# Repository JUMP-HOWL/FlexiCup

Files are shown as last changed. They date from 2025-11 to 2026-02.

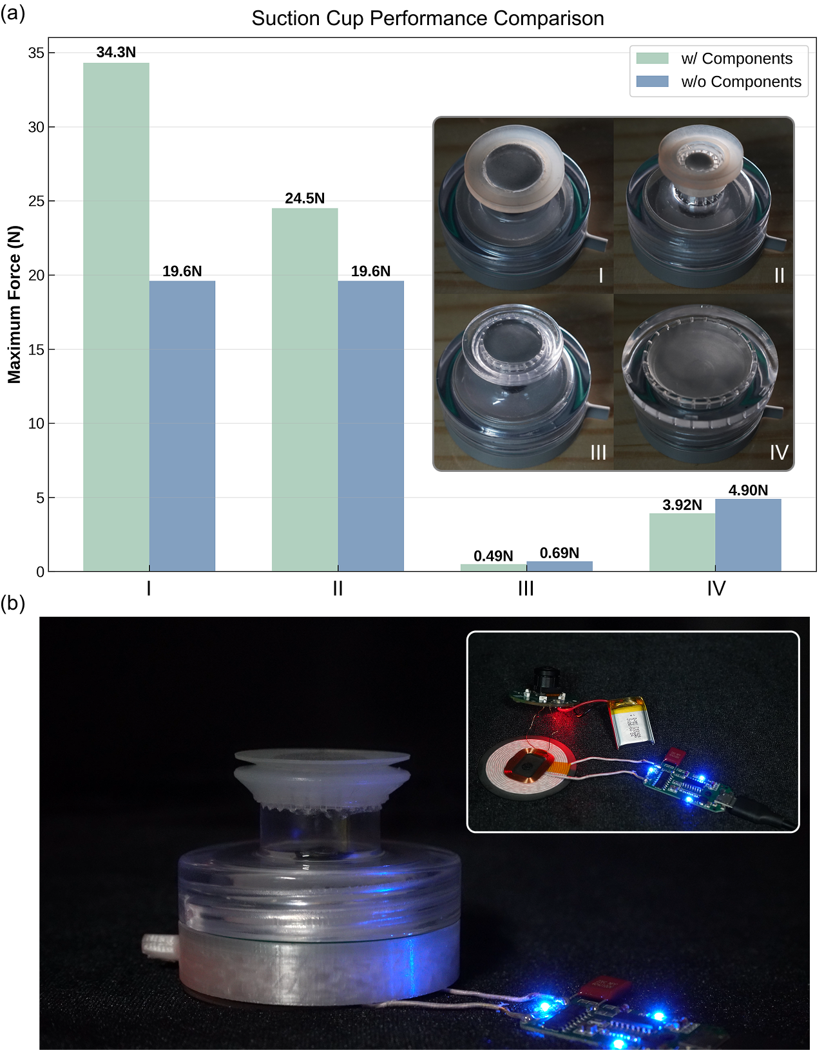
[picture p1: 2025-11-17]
static/images/image/FigBasicCharacterization.png

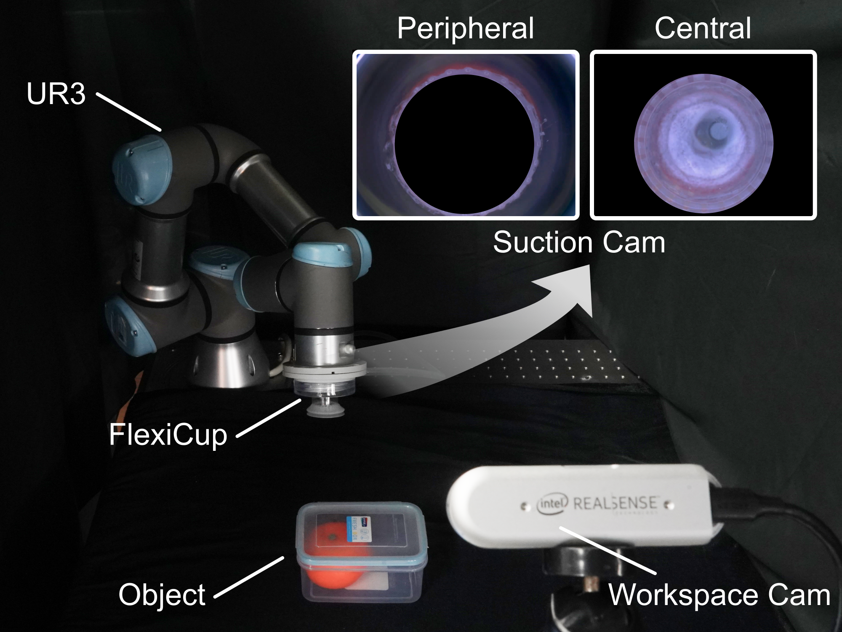
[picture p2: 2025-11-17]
static/images/image/FigExperimentSetup.png

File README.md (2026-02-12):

# FlexiCup: Wireless Multimodal Suction Cup with Dual-Zone Vision-Tactile Sensing

This repository contains the complete project files for FlexiCup—a multimodal suction cup with wireless electronics that integrates dual-zone vision-tactile sensing. The modular mechanical design supports both vacuum and Bernoulli actuation modes while maintaining the identical sensing architecture, demonstrating sensing-actuation decoupling. Included are hardware designs (CAD/STEP, PCB schematics/layout/BOM/Gerber), ESP32-S3 firmware, the full learning pipeline, and documentation.

## 📁 Repository Structure

```
FlexiCup/
├── Hardware/              # Hardware design and firmware
│   ├── Fabrication/       # Physical hardware design files
│   │   ├── CAD/          # 3D CAD models and mechanical designs
│   │   │   ├── FlexiCup_Vacuum.STEP          # Vacuum mode assembly (109MB)
│   │   │   ├── FlexiCup_Bernoulli.STEP       # Bernoulli mode assembly (109MB)
│   │   │   ├── suction cup bottom I.STEP     # Bottom configuration I
│   │   │   ├── suction cup bottom II.STEP    # Bottom configuration II
│   │   │   ├── suction cup bottom III.STEP   # Bottom configuration III
│   │   │   ├── suction cup bottom IV.STEP    # Bottom configuration IV
│   │   │   ├── suction cup top.STEP          # Top assembly
│   │   │   └── FlexiCup_CAD_BOM.xlsx        # CAD Bill of Materials
│   │   │
│   │   └── PCB/          # PCB design files
│   │       ├── FlexiCup_Schematic.pdf        # Circuit schematic
│   │       ├── FlexiCup_PCB.pdf              # PCB layout
│   │       ├── FlexiCup_PCB_BOM.xlsx         # PCB Bill of Materials
│   │       └── Gerber_PCB.zip                # Manufacturing files
│   │
│   └── Firmware/          # Embedded firmware code
│       └── ESPCAM/       # ESP32S3 camera firmware
│           ├── main/     # Main application code
│           │   ├── inc/  # Header files
│           │   │   ├── camera.h
│           │   │   ├── httpServer.h
│           │   │   ├── led.h
│           │   │   └── wifiConnect.h
│           │   ├── src/  # Source files
│           │   │   ├── camera.c
│           │   │   ├── httpServer.c
│           │   │   ├── led.c
│           │   │   └── wifiConnect.c
│           │   ├── html/ # Web interface
│           │   └── main.c # Main entry point
│           │
│           ├── managed_components/  # ESP32-Camera library
│           ├── CMakeLists.txt
│           ├── sdkconfig
│           └── README.md
│
├── Software/              # High-level software and algorithms
│   └── diffusion_policies/ # Diffusion policy implementation
│       ├── data_collect.py  # Data collection pipeline
│       ├── train.py        # Training script
│       ├── deploy.py       # Deployment script
│       ├── environment.yml # Conda environment
│       └── README.md       # Software documentation
│
├── PDF/                   # Documentation
│   └── paper.pdf         # Research paper
│
├── static/               # Website assets
│   ├── css/             # Stylesheets
│   ├── js/              # JavaScript files
│   ├── images/          # Images and figures
│   └── video/           # Video demonstrations
│       ├── optimized/   # Optimized videos for web (12.2MB total)
│       └── websitevideo/# Original high-quality videos
│
└── index.html           # Project website

```

## 🔧 Hardware Files

### Fabrication Design Files
All mechanical and electronic designs are provided for complete system reproduction:

**CAD Models (STEP Format)**
All mechanical designs are provided in STEP format for maximum compatibility:

- **Main Assemblies**:
  - `FlexiCup_Vacuum.STEP` (109MB): Complete vacuum suction mode assembly
  - `FlexiCup_Bernoulli.STEP` (109MB): Complete Bernoulli suction mode assembly

- **Modular Components**:
  - `suction cup top.STEP`: Top housing with camera and electronics
  - `suction cup bottom I-IV.STEP`: Four interchangeable bottom configurations
    - I & II: For vacuum mode operation
    - III & IV: For Bernoulli mode operation

- **Bill of Materials**:
  - `FlexiCup_CAD_BOM.xlsx`: Complete list of mechanical components

**PCB Design Files**
Complete electronics design for the FlexiCup controller:

- **Schematic**: `FlexiCup_Schematic.pdf` - Circuit diagram
- **Layout**: `FlexiCup_PCB.pdf` - PCB layout design
- **BOM**: `FlexiCup_PCB_BOM.xlsx` - Electronic components list
- **Manufacturing**: `Gerber_PCB.zip` - Gerber files for PCB fabrication

**Key Components**:
- ESP32S3 microcontroller with Wi-Fi
- OV5640 camera interface
- LED driver circuits
- Power management (3.7V LiPo battery)
- Wireless charging circuit

### Firmware Code

**ESP32S3 Camera Firmware**
Located in `Hardware/Firmware/ESPCAM/`, built with ESP-IDF framework.

**Main Features**:
- **Camera Control** (`camera.c/h`): OV5640 camera configuration and image capture
- **LED Control** (`led.c/h`): Illumination switching for vision-tactile sensing
- **HTTP Server** (`httpServer.c/h`): Web interface and video streaming
- **Wi-Fi** (`wifiConnect.c/h`): Wireless communication

**Key Specifications**:
- Image Resolution: 640×480 @ 30 Hz
- Streaming: Real-time video over Wi-Fi (UDP)
- Power: 3.7V 300mAh LiPo battery with wireless charging
- Runtime: ~30 minutes continuous operation

**Building the Firmware**
```bash
cd Hardware/Firmware/ESPCAM
idf.py build
idf.py flash
```

## 💻 Software

### Diffusion Policy Implementation
Located in `Software/diffusion_policies/`, this contains the complete machine learning pipeline for contact-aware manipulation.

**Main Components**:
- **Data Collection** (`data_collect.py`): Automated data collection pipeline for demonstration gathering
- **Training** (`train.py`): Diffusion policy training with multimodal observations
- **Deployment** (`deploy.py`): Real-time deployment for robot control
- **Environment** (`environment.yml`): Conda environment with all dependencies

**Key Features**:
- Multimodal fusion of dual-zone vision-tactile data via multi-head attention (8 heads, 512-d)
- Diffusion policy with action chunking (8-step history, 48-step horizon)
- AdamW optimizer with cosine annealing, 500 epochs training
- Real-time inference for robot control at 10 Hz
- Contact-aware manipulation with illumination switching and valve control

**Setup and Usage**
```bash
cd Software/diffusion_policies
conda env create -f environment.yml
conda activate flexicup
python train.py --config configs/flexicup_config.yaml
```

## 📊 System Specifications

### Mechanical
- **Normal Force**: 41.5 N (mean, at −80 kPa vacuum)
- **Shear Force**: 8.34 N (mean)
- **Modes**: Vacuum (sustained-contact adhesion) and Bernoulli (contactless lifting)
- **Configurations**: 4 modular bottom designs (I–II vacuum, III–IV Bernoulli)
- **Material**: Dual-layer PDMS membrane (30:1 base + Ag:PDMS 100:1 reflective layer)

### Electronics
- **Controller**: ESP32-S3 (dual-core, Wi-Fi enabled)
- **Camera**: OV5640 with 180° fisheye lens
- **Resolution**: 640×480 @ 30 Hz
- **Connectivity**: Wi-Fi 802.11 b/g/n (UDP streaming)
- **Power**: 3.7V 300mAh LiPo with wireless charging (12.5 μH coil, 200 mA)
- **Runtime**: ~30 minutes continuous operation

### Sensing
- **Dual-Zone**: Central (switchable vision-tactile via LED control) + Peripheral (continuous spatial awareness)
- **Modality Switching**: Real-time illumination control by ESP32-S3
- **Multimodal Recognition**: 100% accuracy (vs. vision-only 82.5%, tactile-only 46.7%)

## 📄 Documentation

- **Research Paper**: `PDF/paper.pdf`
- **Tutorial**: `TUTORIAL.pdf` - Complete fabrication and deployment guide
- **Companion Website**: `index.html` (view at https://jump-howl.github.io/FlexiCup/)
- **Hardware README**: `Hardware/README.md`
- **Software README**: `Software/diffusion_policies/README.md`

## 🎥 Video Demonstrations

Optimized videos are available in `static/video/optimized/`:
- `overview.mp4`: System overview
- `integrated_show.mp4`: Hardware integration and assembly
- `multimodal_performance.mp4`: Vision-tactile sensing demonstration
- `modular_task.mp4`: Modular perception-driven grasping (vacuum & Bernoulli)
- `dptask1.mp4`: Inclined transport task (diffusion policy)
- `dptask2.mp4`: Orange extraction task (diffusion policy)
- `baseline1.mp4` / `baseline2.mp4`: BC-RNN baseline comparisons
- `Wafer_Bernoulli.mp4` / `Wafer_Vaccum.mp4`: Wafer handling comparison
- `Move_Orange.mp4` / `Move_Bottle.mp4`: Dynamic performance evaluation

## 🚀 Getting Started

### Hardware Assembly
1. Review CAD models in `Hardware/Fabrication/CAD/`
2. Fabricate PCB using files in `Hardware/Fabrication/PCB/`
3. Follow BOM files for component sourcing
4. Assemble according to CAD models

### Firmware Setup
1. Install ESP-IDF framework
2. Navigate to `Hardware/Firmware/ESPCAM/`
3. Configure Wi-Fi settings in `main/src/wifiConnect.c`
4. Build and flash firmware

### Software Setup
1. Set up the diffusion policy environment:
   ```bash
   cd Software/diffusion_policies
   conda env create -f environment.yml
   conda activate flexicup
   ```
2. Collect training data or use provided datasets
3. Train the diffusion policy model
4. Deploy for real-time robot control

### Testing
1. Power on the device
2. Connect to FlexiCup Wi-Fi network
3. Access web interface via browser
4. Test vision and tactile sensing modes
5. Run software algorithms for manipulation tasks

<!-- ## 📝 Citation

If you use this work in your research, please cite:

```bibtex
@article{flexicup2025,
  title={FlexiCup: Wireless Multimodal Suction Cup with Dual-Zone Vision-Tactile Sensing},
  author={Anonymous},
  journal={Under Review},
  year={2025}
}
``` -->

## 📧 Contact

For questions or collaboration inquiries, please refer to the paper for contact information.

## 📜 License

This project is licensed under Creative Commons Attribution-ShareAlike 4.0 International License.

---

**Note**: Large CAD files (*.STEP) are managed with Git LFS. Clone with `git lfs clone` to download all files.

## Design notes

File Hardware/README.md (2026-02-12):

# FlexiCup Hardware

This directory contains all hardware-related files for the FlexiCup system, including physical fabrication designs and embedded firmware.

## Directory Structure

- **Fabrication/**: Physical hardware design files
  - **CAD/**: 3D mechanical designs (STEP format) and BOM
  - **PCB/**: Electronic circuit schematics, layout, BOM, and Gerber files
- **Firmware/**: ESP32-S3 embedded firmware
  - **ESPCAM/**: Camera control, LED switching, and wireless communication

## Overview

The FlexiCup hardware implements a modular layered architecture:

1. **Mechanical System**: Modular suction cup with reconfigurable bottom housings supporting vacuum (sustained-contact adhesion) and Bernoulli (contactless lifting) modes. Four bottom configurations (I–IV) accommodate different membrane diameters and actuation principles.
2. **Electronics**: ESP32-S3 controller with OV5640 camera (180° fisheye), WS2812 LED arrays, wireless charging (3.7V 300mAh LiPo), streaming 640×480 @ 30 Hz over Wi-Fi.
3. **Pneumatic System**: Vacuum pump (750 W, 140 L/min, −90 kPa max) and air compressor (800 W, 65 L/min, 0.8 MPa) for the respective modes. Solenoid valves controlled wirelessly by the onboard microcontroller.

## Key Performance

- **Normal Force**: 41.5 N (mean, at −80 kPa)
- **Shear Force**: 8.34 N (mean)
- **Sensing**: Dual-zone vision-tactile (central switchable + peripheral continuous)
- **Runtime**: ~30 minutes wireless operation

## Getting Started

### Fabrication
1. Review CAD models in `Fabrication/CAD/`
2. Fabricate PCB using files in `Fabrication/PCB/`
3. Source components according to BOM files
4. Assemble following the CAD designs

### Firmware
1. Install ESP-IDF framework (v5.0.2)
2. Navigate to `Firmware/ESPCAM/`
3. Configure Wi-Fi settings and build
4. Flash to ESP32-S3 device

For detailed fabrication and assembly instructions, see `TUTORIAL.pdf` in the repository root.

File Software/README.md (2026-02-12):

# FlexiCup Software

This directory contains the high-level software components for the FlexiCup system, focusing on diffusion-based policy learning for contact-aware manipulation.

## Directory Structure

- **diffusion_policies/**: Complete diffusion policy implementation
  - Data collection pipeline (keyboard teleoperation)
  - Training scripts and Hydra configurations
  - Evaluation and deployment code

## Overview

The FlexiCup software stack provides:

1. **Multimodal Observation Encoding**: Workspace camera (D435), dual-zone suction camera (peripheral + central), and robot state processed through parallel ResNet-18 encoders
2. **Multi-Head Attention Fusion**: 8-head, 512-d attention coordinating central and peripheral features during vision-tactile transitions
3. **Diffusion Policy**: DDPM-based action generation with action chunking (8-step history, 48-step horizon), outputting robot joints, illumination switching, and valve state
4. **Training**: AdamW optimizer with cosine annealing, 500 epochs, batch size 16 on RTX 4090

## Experimental Results

- **Inclined Transport**: 73.3% success rate (150 demos, 30 eval trials)
- **Orange Extraction**: 66.7% success rate (100 demos, 30 eval trials)
- **Multi-head attention improvement**: +13% over baseline without attention
- **BC-RNN baseline**: 0% success on both tasks

## Getting Started

### Environment Setup
```bash
cd diffusion_policies
conda env create -f environment.yml
conda activate diffusion_policies
pip install -e .
```

### Basic Usage
1. **Data Collection**: Use `data_collect.py` to gather demonstration data via kinesthetic teaching (30 Hz, downsampled to 10 Hz)
2. **Training**: Run `train.py` with appropriate configuration files
3. **Evaluation**: Test trained models using `eval.py`
4. **Deployment**: Deploy to real robot using `deploy.py`

For detailed documentation, see the README in the `diffusion_policies/` subdirectory.

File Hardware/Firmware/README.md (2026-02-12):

# FlexiCup Firmware

This directory contains the ESP32-S3 firmware for the FlexiCup system, built with the ESP-IDF framework (v5.0.2).

## Components

- **Camera Module** (`camera.c/h`): OV5640 camera configuration and 640×480 @ 30 Hz image capture
- **LED Control** (`led.c/h`): WS2812 addressable RGB LED illumination switching for vision-tactile modality control
- **HTTP Server** (`httpServer.c/h`): Web interface and real-time video streaming
- **Wi-Fi** (`wifiConnect.c/h`): Wireless communication and UDP image streaming

## Key Specifications

- **Resolution**: 640×480 @ 30 Hz
- **Streaming**: Real-time video over Wi-Fi (UDP)
- **Power**: 3.7V 300mAh LiPo battery (~30 min runtime)
- **Charging**: Wireless charging at 200 mA (12.5 μH coil)

## Building and Flashing

```bash
cd Hardware/Firmware/ESPCAM
idf.py build
idf.py -p /dev/ttyUSB0 flash
```

See `TUTORIAL.pdf` in the repository root for detailed flashing procedures including boot mode selection and USB-to-TTL connections.

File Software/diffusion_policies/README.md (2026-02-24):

# Diffusion Policies for FlexiCup Contact-Aware Manipulation

A diffusion policy framework for contact-aware suction manipulation, processing multimodal observations (workspace camera, dual-zone vision-tactile suction camera, robot state) through parallel ResNet-18 encoders with multi-head attention fusion.

## Project Structure

```
diffusion_policies/
├── diffusion_policies/           # Core code package
│   ├── common/                   # Common utilities
│   ├── config/                   # Configuration files
│   │   ├── task/                # Task configurations
│   │   │   ├── slope_task.yaml  # Slope task configuration
│   │   │   └── valve_task.yaml  # Valve task configuration
│   │   ├── slope_policy.yaml    # Slope task policy configuration
│   │   └── valve_policy.yaml    # Valve task policy configuration
│   ├── dataset/                  # Dataset processing
│   │   ├── valve_task_dataset.py # Valve task dataset
│   │   └── ...                  # Other dataset implementations
│   ├── env/                      # Environment interfaces
│   ├── env_runner/              # Environment runners
│   ├── gym_util/                # Gym environment utilities
│   ├── model_dp3/               # DP3 model implementation
│   ├── model_dp_umi/            # DP-UMI model implementation
│   ├── model_idp3/              # IDP3 model implementation
│   ├── policy/                  # Policy implementations
│   │   ├── diffusion_unet_hybrid_image_policy.py  # Main policy for valve/slope tasks
│   │   └── ...                  # Other policy implementations
│   ├── workspace/               # Training workspaces
│   └── workspace_quad/          # Quadruped robot workspace
├── data_collect.py              # Data collection script
├── train.py                     # Training script
├── deploy.py                    # Deployment script
├── eval.py                      # Evaluation script
├── setup.py                     # Installation configuration
├── environment.yml              # Conda environment configuration
└── README.md                    # Project documentation
```

## Environment Setup

```bash
# Create and activate conda environment
conda env create -f environment.yml
conda activate diffusion_policies

# Install the project package
pip install -e .
```

## Hardware Requirements

### Required Hardware
- **Robot**: Universal Robots UR3 with RTDE interface support
- **Cameras**: Intel RealSense D435 (workspace) + FlexiCup ESP32-S3 suction camera (dual-zone)
- **Suction Cup**: FlexiCup with wireless electronics (vacuum Configuration I for learning tasks)
- **Computing Device**: CUDA-capable GPU (RTX 4090 recommended)

### Network Configuration
- Robot IP: `192.168.10.99`
- ESP32 Camera IP: `192.168.10.53:8000`
- ESP32 Controller IP: `192.168.10.4:3333`

## Data Collection

### Start Data Collection

```bash
python data_collect.py
```

### Control Instructions

| Key | Function |
|-----|---|
| `SPACE` | Start/end trial recording |
| `↑↓←→` | Move TCP in X-Y plane |
| `W/S` | Move TCP up/down |
| `V` | Toggle valve state |
| `R` | Return to home position |
| `J` | Toggle tactile/visual mode |
| `Q` | Quit program (in display window) |

### Data Format

Collected data is saved in `dataset_continuous/session_YYYYMMDD_HHMMSS/` directory:

- `data.csv`: Robot states and sensor data
- `video.mp4`: Synchronized video recording
- `markers.json`: Trial marker information

Data contains the following fields:
- `tcp_pose_0-5`: TCP pose (position + orientation)
- `joint_angle_0-5`: Joint angles
- `valve_state`: Valve state
- `is_tactile_mode`: Tactile mode flag
- `trial_id`: Trial ID

## Model Training

### Configure Training Parameters

Edit configuration files `diffusion_policies/config/slope_policy.yaml` (inclined transport) or `valve_policy.yaml` (orange extraction):

```yaml
# Data path
zarr_path: /path/to/your/dataset.zarr

# Training parameters
training:
  num_epochs: 500
  batch_size: 16
  lr: 1.0e-4
  optimizer: adamw
  lr_scheduler: cosine
  device: cuda:0

# Model parameters
policy:
  horizon: 48
  n_obs_steps: 8
  n_action_steps: 24
  enable_esp_cross_attention: true  # multi-head attention for dual-zone
```

### Start Training

```bash
# Train inclined transport task
python train.py --config-name=slope_policy

# Train orange extraction task
python train.py --config-name=valve_policy

# Specify GPU
CUDA_VISIBLE_DEVICES=0 python train.py --config-name=slope_policy
```

### Training Monitoring

- Training logs saved in `data/outputs/` directory
- Supports Weights & Biases monitoring
- Automatic best model checkpoint saving

## Model Deployment

### Start Deployment

```bash
python deploy.py --checkpoint /path/to/model.ckpt
```

### Deployment Features

- **Multimodal Perception**: Fuses D435 workspace camera and FlexiCup dual-zone suction camera
- **Real-time Inference**: 10 Hz control frequency with action chunking
- **Illumination Control**: Automatic LED switching for vision-tactile transitions
- **Safety Mechanisms**: Anomaly detection and emergency stop
- **State Monitoring**: Real-time display of robot state and prediction results

### Deployment Configuration

The deployment script automatically:
1. Connects all hardware devices
2. Loads the trained model
3. Starts camera capture threads
4. Begins real-time control loop

## Model Evaluation

```bash
# Evaluate model performance
python eval.py --checkpoint /path/to/model.ckpt --config-name=slope_policy

# Generate evaluation report
python eval.py --checkpoint /path/to/model.ckpt --output-dir ./eval_results
```

## Supported Tasks

### 1. Inclined Transport Task
- **Objective**: Position above inclined surface (5°/10°/15°), search for contact region, adjust tilt via tactile feedback, verify contact, and lift
- **Demonstrations**: 150 demos collected via kinesthetic teaching at 30 Hz, downsampled to 10 Hz
- **Configuration**: `slope_policy.yaml`
- **Success Rate**: 73.3% (full system), with +13% from multi-head attention
- **Key Features**:
  - Multi-head attention (8 heads, 512-d) for dual-zone feature coordination
  - Action chunking: 8-step history, 48-step horizon
  - Random cropping augmentation (76×76 from 224×224)

### 2. Orange Extraction Task
- **Objective**: Remove transparent cover in vision mode, realign above orange, then Tactile-aware grasping with LED-enabled contact detection
- **Demonstrations**: 100 demos collected via kinesthetic teaching at 30 Hz, downsampled to 10 Hz
- **Configuration**: `valve_policy.yaml`
- **Success Rate**: 66.7% (full system)
- **Key Features**:
  - Multimodal vision-tactile fusion with illumination switching control
  - Contact-aware manipulation of deformable objects
  - Coordinated valve timing and modality transitions

## Model Architecture

### Core Features
- **Diffusion Policy**: DDPM-based action generation with action chunking
- **Multimodal Fusion**: Workspace vision + dual-zone suction camera (peripheral + central) + robot state
- **Multi-Head Attention**: 8-head, 512-d attention coordinating central and peripheral features
- **Action Space**: Robot joints (6-DoF), illumination switching, pneumatic valve state

### Network Structure
- **Observation Encoders**: Three parallel ImageNet-pretrained ResNet-18 (workspace, peripheral, central) + 2-layer MLP for state
- **Feature Integration**: Multi-head attention on dual-zone features → concatenation with workspace features and state
- **Diffusion Network**: 1D U-Net conditional generation network (DDPM)
- **Training**: AdamW optimizer, cosine annealing, 500 epochs, batch size 16

## Development Guide

### Adding New Tasks

1. Create task configuration file `config/task/new_task.yaml`
2. Implement dataset class `dataset/new_task_dataset.py`
3. Create policy configuration `config/new_task_policy.yaml`
4. Run training and evaluation

### Custom Models

1. Inherit from `BaseImagePolicy` or `BasePointCloudPolicy`
2. Implement `predict_action()` method
3. Specify new model class in configuration file

### Hardware Integration

1. Implement hardware driver interfaces
2. Modify hardware initialization code in `deploy.py`
3. Update data collection scripts

## Troubleshooting

### Common Issues

1. **CUDA Out of Memory**
   ```bash
   # Reduce batch size
   python train.py dataloader.batch_size=8
   ```

2. **Camera Connection Failed**
   ```bash
   # Check device connection
   lsusb | grep Intel
   # Restart RealSense service
   sudo systemctl restart realsense
   ```

3. **Robot Connection Timeout**
   ```bash
   # Check network connection
   ping 192.168.10.99
   # Check RTDE service status
   ```

4. **Slow Training Convergence**
   - Check data quality and annotations
   - Adjust learning rate and batch size
   - Use pre-trained weights

### Log Analysis

- Training logs: `data/outputs/*/train.log`
- Deployment logs: `deploy_multimodal_log.txt`
- Error logs: Check terminal output and exception stack traces

## Performance Optimization

### Training Optimization
- Use mixed precision training: `training.use_amp=true`
- Data parallelism: `CUDA_VISIBLE_DEVICES=0,1 python train.py`
- Gradient accumulation: `training.gradient_accumulate_every=2`

### Inference Optimization
- Model quantization: Use TensorRT or ONNX
- Batch inference: Process multiple observations simultaneously
- Asynchronous processing: Separate perception and control threads

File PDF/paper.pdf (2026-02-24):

IEEE ROBOTICS AND AUTOMATION LETTERS, VOL. XX, NO. X, XXX 2025 | 1

# FlexiCup: Wireless Multimodal Suction Cup with Dual-Zone Vision-Tactile Sensing

Abstract—Conventional suction cups lack sensing capabilities for contact-aware manipulation in unstructured environments. This paper presents FlexiCup, a multimodal suction cup with wireless electronics that integrate dual-zone vision-tactile sensing. The central zone dynamically switches between vision and tactile modalities via illumination control, while the peripheral zone provides continuous spatial awareness. The modular mechanical design supports both vacuum (sustained-contact adhesion) and Bernoulli (contactless lifting) actuation while maintaining the identical dual-zone sensing architecture, demonstrating sensing-actuation decoupling where sensing and actuation principles are orthogonally separable. We validate hardware versatility through dual control paradigms. Modular perception-driven grasping achieves comparable success rates across vacuum (90.0%) and Bernoulli (86.7%) modes using identical sensing and control pipelines, validating the sensing architecture’s effectiveness across fundamentally different pneumatic principles. Diffusion-based end-to-end learning achieves 73.3% and 66.7% success on contact-aware manipulation tasks, with ablation studies confirming 13% improvements from multi-head attention coordinating dual-zone observations. Hardware designs, firmware, and experimental videos are available at the companion website: https://anonymous.4open.science/api/repo/FlexiCup-DA7D/file/index.html?v=8f531b44. (https://anonymous.4open.science/api/repo/FlexiCup-DA7D/file/index.html?v=8f531b44)

Index Terms—Multimodal sensing, Suction manipulation, Vision-tactile sensing, Policy learning

I. INTRODUCTION
S

UCTION cups have been widely adopted in robotic manipulation for handling diverse object geometries [1]–[5]. Effective manipulation in unstructured environments requires target identification, obstacle detection, contact verification, and surface adaptation. Traditional suction systems rely on preprogrammed trajectories without sensing feedback [6], [7]. Recent efforts have integrated sensing into suction cups to enable contact-aware manipulation. Camera-based tactile systems [8], [9] achieve high-resolution contact imaging but dedicate their entire optical field to the tactile membrane, sacrificing peripheral spatial awareness. Systems using external cameras [2], [10] can observe the workspace but suffer from occlusion during contact. These architectural constraints force a trade-off: existing sensory suction systems must choose between high-resolution contact sensing and spatial context awareness.
The visuotactile sensing community has demonstrated that coordinating vision and tactile observations enables robust manipulation under varied conditions [11]–[14]. However, these systems typically employ gripper-based designs [15], [16] that require opposing contact surfaces or graspable features, limiting their applicability to scenarios such as handling flat featureless objects or accessing confined spaces with restricted side clearance.

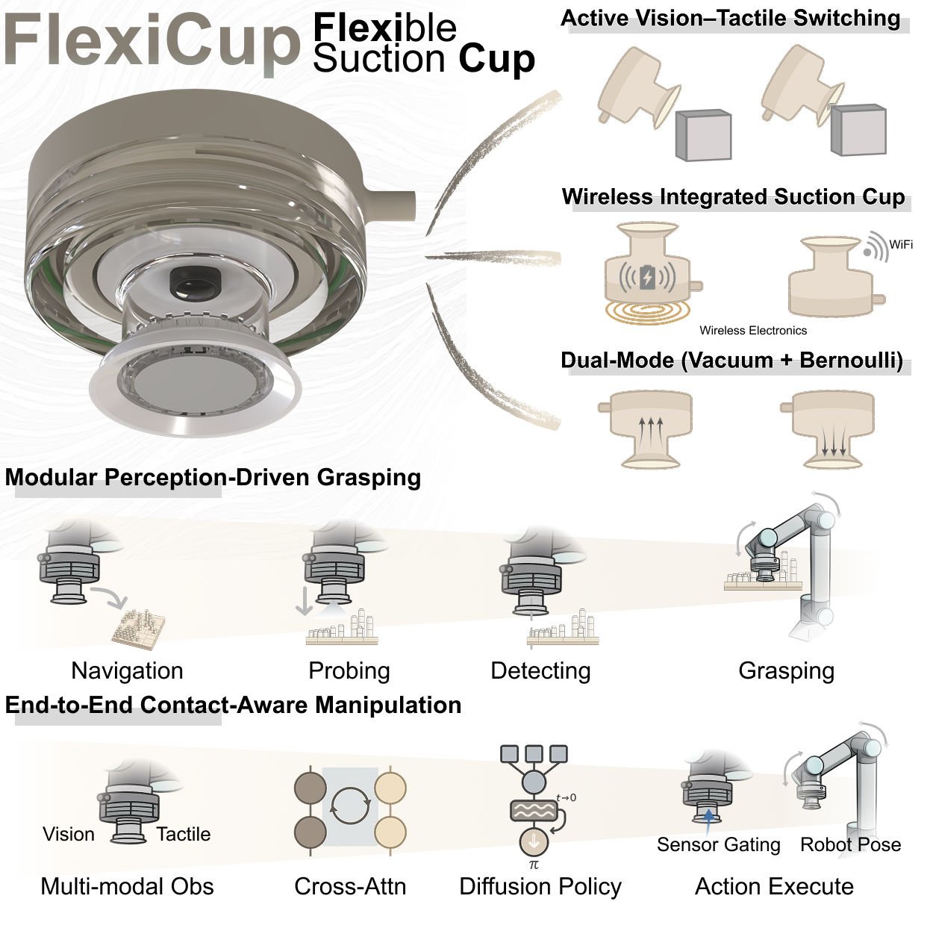
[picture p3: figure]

Fig. 1. FlexiCup overview showing hardware features (top), modular perception-driven grasping approach (middle), and end-to-end learning framework (bottom). The system integrates active vision-tactile switching, wireless operation, and vacuum-based contact manipulation through a modular hardware architecture.

Motivated by these advances in multimodal sensing, we present FlexiCup, a wireless multimodal suction cup that addresses the architectural limitations in existing sensory suction systems through dual-zone vision-tactile sensing while operating in manipulation scenarios where gripper-based approaches face geometric constraints (Fig. 1). A key insight is decoupling sensing from actuation: the dual-zone vision-tactile architecture operates across both vacuum and Bernoulli pneumatic principles. The architecture implements dual-zone sensing: a central zone switches between vision and tactile modalities via illumination control, while a peripheral zone maintains continuous spatial awareness.
This architecture enables adaptive manipulation requiring coordinated visual search, obstacle avoidance, and contact verification—capabilities that existing sensory suction systems cannot simultaneously provide. By overcoming the morphological constraints of gripper-based counterparts on flat or confined targets, FlexiCup validates its efficacy through experiments on varying obstacle densities, confined space extraction, and multi-phase manipulation sequences requiring continuous feedback loop.
The key contributions of this work include:

IEEE ROBOTICS AND AUTOMATION LETTERS, VOL. XX, NO. X, XXX 2025 | 2

TABLE I
COMPARISON OF REPRESENTATIVE SUCTION CUP PERCEPTION SYSTEMS
Work | Mechanism | Modality | Perception Type | Force | Method | Deployment
Doi et al. [6] | Vacuum | Tactile | Capacitive | — | Stroke-based State Decision | Wired
Aoyagi et al. [7] | Vacuum | Tactile | Piezoresistive | — | Multi-cup Force Reasoning | Wired
Lee et al. [2] | Vacuum | Tactile | Pressure-based | 19 N | Model-based Haptic Search | Wired
Shahabi et al. [17] | Vacuum | Tactile | Piezoresistive | — | ML-based Property Regression | Wired
van Veggel et al. [8] | Vacuum | Tactile | Vision-based | 9.35 N | CNN-based Pose Correction | Wired
Yue et al. [18] | Vacuum | Tactile | Pressure-based | — | Hierarchical Embodied Control | Wired
Jang et al. [19] | Vacuum | Tactile | Pressure-based | 2.8 N | Closed-loop Force Regulation | Wired
Ours | Vacuum / Bernoulli | Vision + Tactile | Vision-based | 41.5 N | Modular Perception Driven
| | | | | / Diffusion-based Imitation Learning | Wireless
- Sensing-actuation decoupling through modular design,
enabling identical sensing and control pipelines across vacuum and Bernoulli modes.
- Dual-zone vision-tactile architecture with wireless electronics, implementing illumination-controlled modality switching between contact imaging and spatial context.
- Dual-paradigm validation combining modular grasping (90.0% vacuum, 86.7% Bernoulli) and diffusion-based learning with multi-head attention, confirmed by ablation studies and baseline comparisons.

II. RELATED WORK

Suction manipulation has advanced through diverse sensing modalities (Table I). Early systems employed capacitive [6] and piezoresistive [7], [17] sensing for basic contact detection, while pressure-based approaches [2], [18], [19] enabled model-based haptic search and force regulation. Recent camera-based tactile sensors [8], [20], building on foundational vision-based tactile technologies [21]–[23], achieve high-resolution deformation imaging but dedicate their entire optical field to contact sensing, precluding simultaneous spatial awareness. Integration challenges remain: electronic tactile arrays can compromise pneumatic sealing, while maintaining perception throughout contact-to-non-contact transitions requires architectural solutions beyond single-modality designs. Control paradigms have similarly evolved from classical planning [2], [24] to learning-based methods [8], [17], [25]– [27], yet deployment constraints persist—existing systems require wired connections for high-bandwidth sensing. This work addresses these limitations through wireless electronics, dual-zone vision-tactile architecture enabling modality switching, and modular dual-mode design supporting both classical and diffusion-based control while achieving 41.5 N force capacity.

III. HARDWARE DESIGN

The FlexiCup hardware addresses the trade-off between contact imaging and spatial awareness by realizing dual-zone vision–tactile sensing in a wireless, modular suction morphology. It implements a layered pneumatic–optical–electronic stack and interchangeable bottom housings that decouple sensing from actuation while remaining compatible with both vacuum and Bernoulli principles; the following subsections detail the guiding design principles and system architecture.

A. Design Principles

FlexiCup integrates vision and tactile modalities within a unified optical framework, employs wireless electronics to eliminate electrical tethering, and implements modular mechanical design enabling dual-mode operation with complementary actuation mechanisms—vacuum for contact-based adhesion and Bernoulli for contactless lifting—while maintaining identical core electronics and dual-zone sensing architecture.

B. System Architecture and Integration

The system adopts a modular layered architecture integrating pneumatic actuation, electronic control, and optical sensing (Fig. 2(a)). The modular design separates task-specific pneumatic actuation in the bottom housing from shared electronic control and optical sensing in the top layer, enabling rapid reconfiguration between suction modes.
The bottom housing provides the pneumatic interface and contact surface, with a central groove accommodating the PDMS membrane for sealing and sensing. Pneumatic airways route around the membrane perimeter, physically separating actuation from sensing. The airway geometry differs between Vacuum and Bernoulli configurations, while the membrane mounting interface remains consistent. The bottom housing engages with the top through threaded connection with fluoroelastomer O-ring seal.
The top housing mounts a PCB assembly centered on an ESP32S3 microcontroller (3.7 V, 300 mAh battery, 12.5 µH wireless charging coil), streaming 640×480 images at 30 Fps over Wi-Fi. The battery provides approximately 30 minutes of continuous operation, with thermal management facilitated by pneumatic airflow and 2-hour wireless charging at 200 mA (Fig. 2(b,c)). This electronic module remains identical across both suction modes, enabling wireless operation with electrical decoupling from the robot arm.
The top housing integrates an optical sensing system below the electronic module, comprising an OV5640 camera with 180° fisheye lens and LED arrays enabling dual-zone perception through the tactile membrane interface.
The pneumatic control system employs distinct configurations: vacuum mode utilizes a vacuum pump (750 W, 140 L/min) at -90 kPa maximum pressure, achieving 41.5 N normal force at -80 kPa, while Bernoulli mode relies on an air compressor (800 W, 65 L/min) with supply pressure up to

IEEE ROBOTICS AND AUTOMATION LETTERS, VOL. XX, NO. X, XXX 2025 | 3

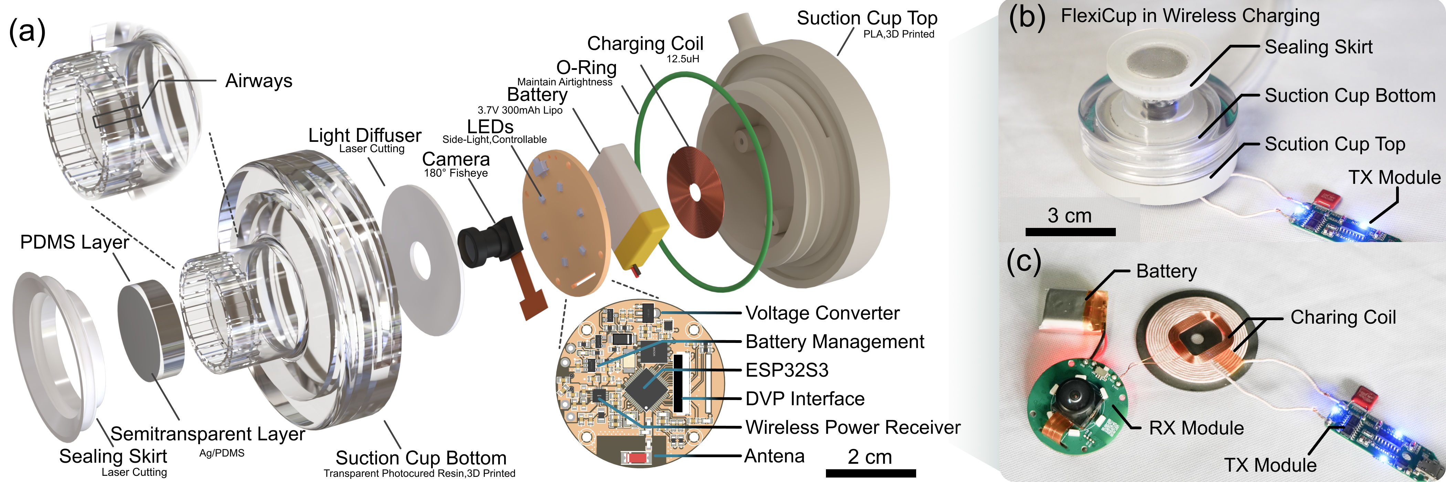
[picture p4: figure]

Fig. 2. System architecture showing (a) modular component integration, (b) wireless charging configuration, and (c) standalone charging module.

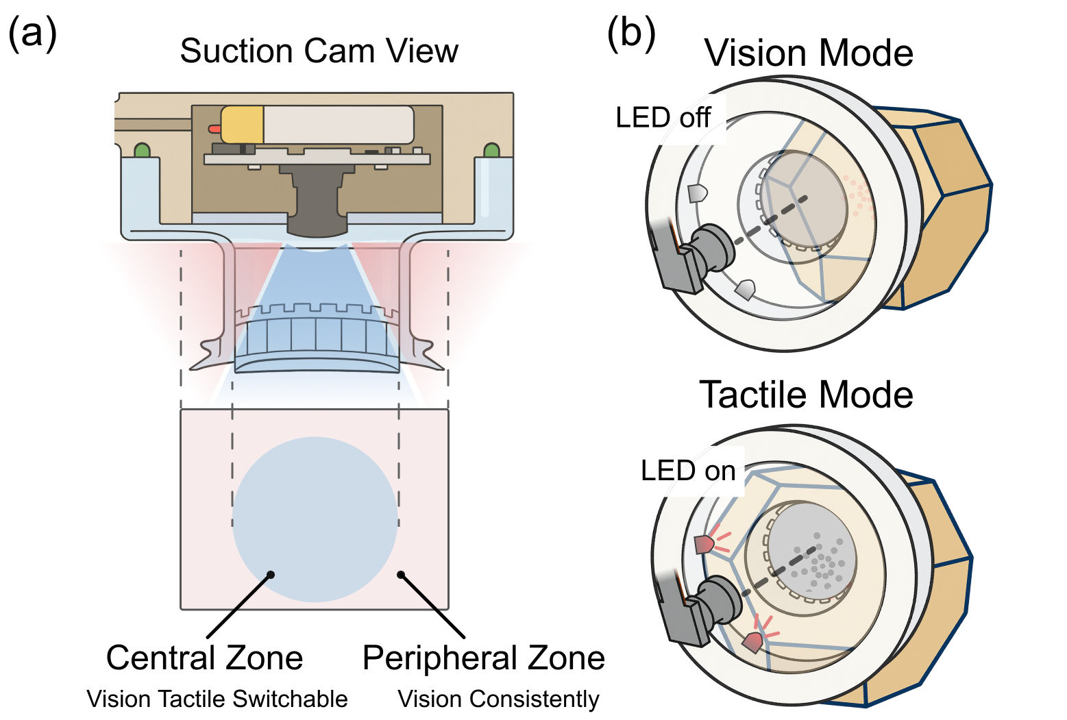
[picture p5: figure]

Fig. 3. Vision-tactile sensing showing (a) dual-zone camera view and (b) modality switching via illumination control.

### 0.8 MPa. Pneumatic actuation is controlled wirelessly through

solenoid valves triggered by the onboard microcontroller. The standardized interface enables rapid reconfiguration by exchanging the bottom housing and connecting to the corresponding pneumatic source.

C. Vision-Tactile Sensing System

The 180° fisheye camera captures two functional zones: the central zone enables switchable vision-tactile sensing, while the peripheral zone provides continuous visual awareness (Fig. 3(a)).
The system switches modalities through illumination control in real-time by the ESP32S3 microcontroller with dynamic camera exposure and gain adjustments (Fig. 3(b)). In vision mode, LEDs remain inactive, allowing ambient light through the membrane for object detection. In tactile mode, LEDs illuminate the membrane internally, imaging deformations induced by contact forces. The semitransparent PDMS membrane exhibits ambient light sensitivity, addressed through high-intensity internal LEDs with optimized fisheye lens and camera exposure settings, though tactile features may become

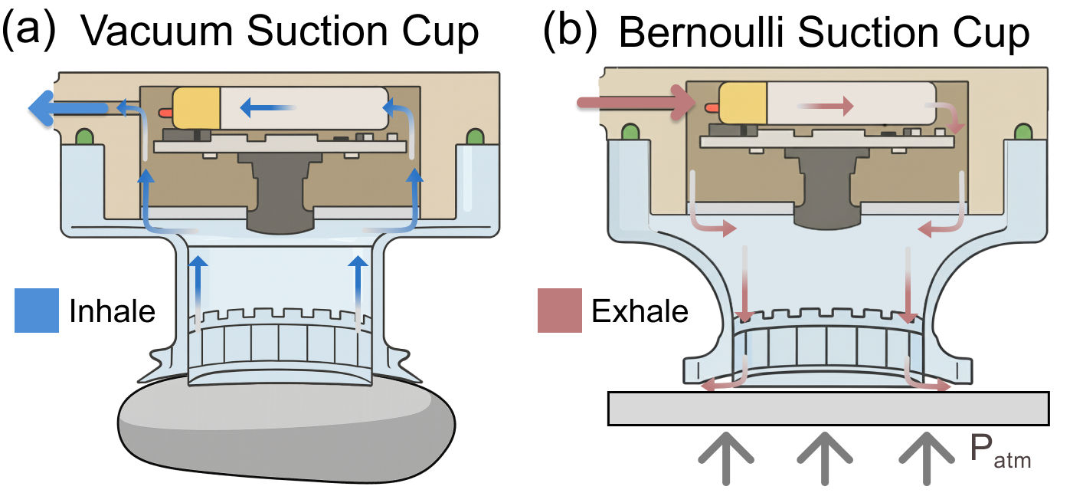
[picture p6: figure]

Fig. 4. Dual-mode suction mechanisms demonstrating complementary actuation principles. (a) Vacuum mode generates adhesion through inward airflow requiring sustained contact. (b) Bernoulli mode creates lifting force through outward airflow enabling contactless lifting. Both modes share the identical dual-zone vision-tactile sensing architecture.

less pronounced under exceptionally strong environmental lighting.

D. Dual-Mode Suction Mechanisms with Complementary Sensing
Vacuum mode generates adhesion through negative pressure, requiring sustained contact that induces continuous membrane deformation, enabling dense tactile feedback throughout manipulation for deformable object handling and surface compliance detection (Fig. 4(a)).
Bernoulli mode creates contactless lifting through outward airflow (Fig. 4(b)), with the dual-zone architecture supporting visual perception and tactile verification during positioning. Both modes share identical sensing pipelines, confirming sensing-actuation decoupling where mode selection depends on task requirements rather than sensing constraints.
E. PDMS Membrane Design
The PDMS membrane provides tactile sensing and sealing through contact-induced deformation (Fig. 5(a)). The dual-layer system (Fig. 5(b)) employs a PDMS base layer (30:1 mass ratio, 70°C for 4 hours) providing compliance that captures surface details, and a semitransparent layer (Ag:PDMS

IEEE ROBOTICS AND AUTOMATION LETTERS, VOL. XX, NO. X, XXX 2025 | 4

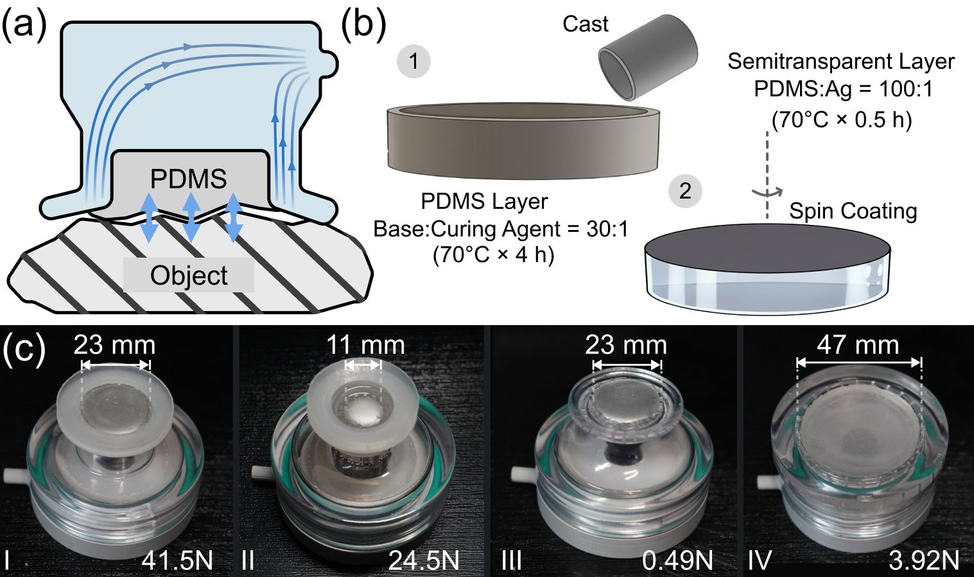
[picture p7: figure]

Fig. 5. | PDMS membrane design and fabrication. (a) PDMS membrane
deformation during contact. (b) Dual-layer membrane fabrication process. (c) Four modular configurations (I-IV).

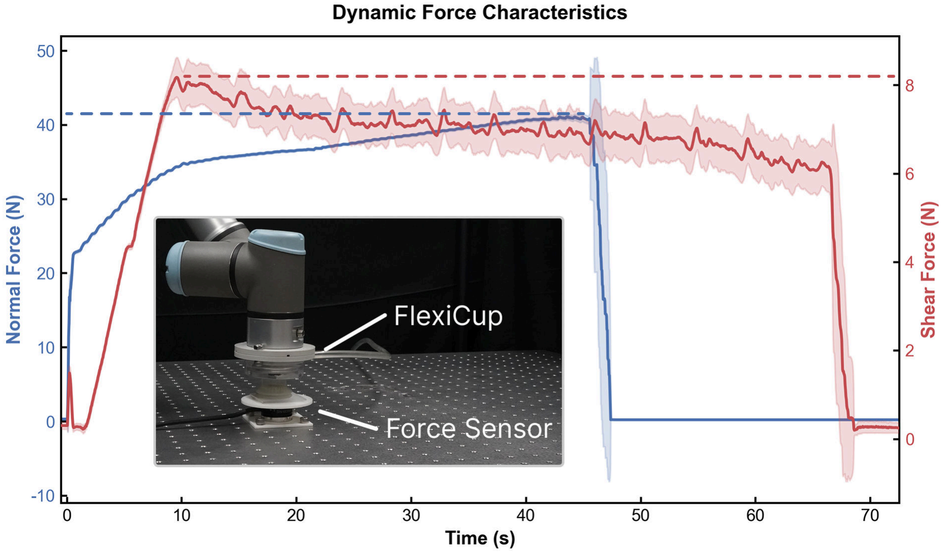
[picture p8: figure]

Fig. 6. Force characteristics from vacuum mode. Blue curve: normal force evolution during vertical pull-off from contact to detachment. Red curve: shear force evolution during horizontal drag from contact to detachment. Inset: experimental setup with FlexiCup mounted on robot arm and force sensor fixed on platform.

100:1, 70°C for 0.5 hours) providing the reflective surface for photometric tactile imaging. Four modular bottom configurations (I-IV, Fig. 5(c)) implement varying membrane diameters for vacuum operation. Configurations I-II are optimized for deformable objects and tactile sensitivity. Adhesion force ranges from sub-Newton to over 40 N across configurations. Configuration selection requires only bottom housing replacement while all sensing components remain unchanged.

F. Force Characteristics from Vacuum Mode

To characterize suction performance, we conducted automated force measurements using a 6-axis force/torque sensor on a smooth acrylic surface at -80 kPa vacuum pressure. The test protocol included normal pull-off tests measuring detachment force and horizontal drag tests measuring shear resistance, with each test repeated 20 times. The averaged force profiles (Fig. 6) reveal transient behaviors during attachment and detachment. Results demonstrate mean maximum normal force of 41.5 N and shear force of 8.34 N, exceeding theoretical predictions (F = P × A ≈ 33.2 N) due to structural compliance increasing the effective sealing area.

G. Multimodal Sensing Validation

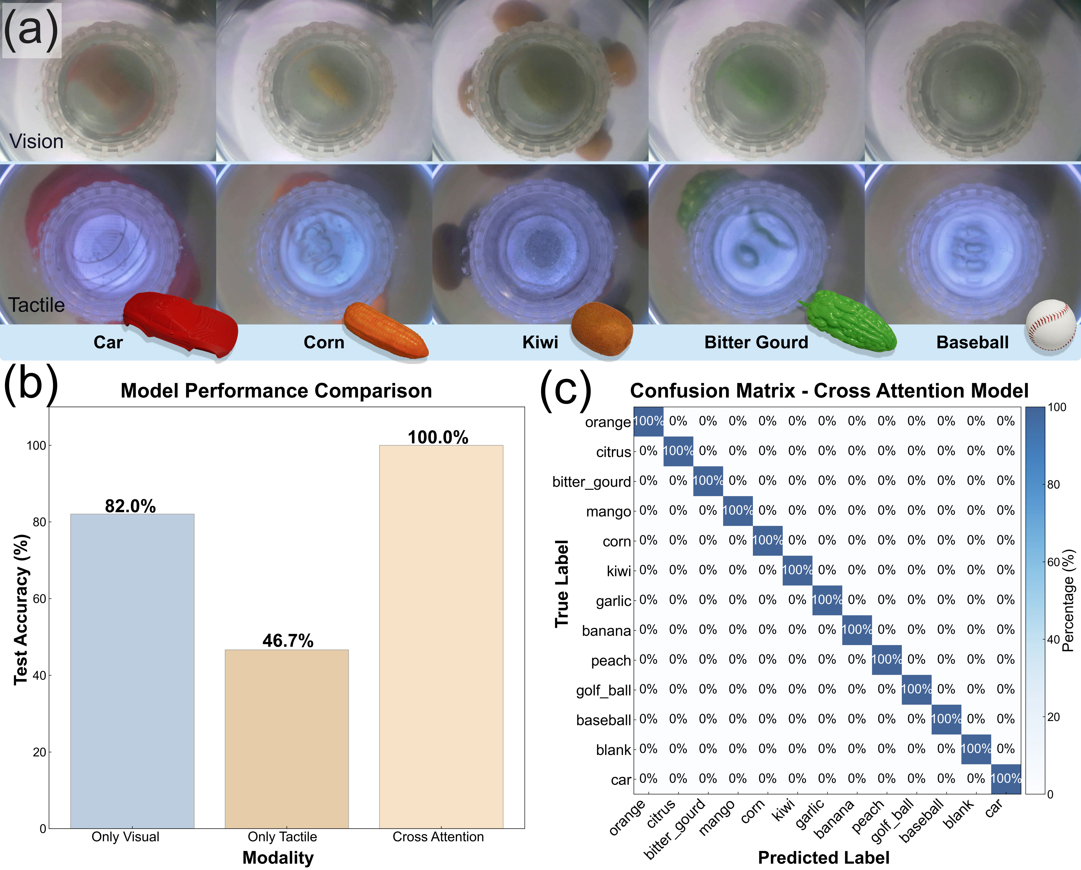
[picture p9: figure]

Fig. 7. Multimodal recognition validation showing (a) vision-tactile sensing comparison across objects, (b) accuracy comparison (vision-only: 82.5%, tactile-only: 46.7%, multi-head attention: 100%), and (c) confusion matrix.

We conducted object recognition experiments across thirteen objects (Fig. 7(a)). Using ImageNet-pretrained ResNet-18, vision-only achieves 82.5%, tactile-only 46.7%, and multi-head attention fusion 100% accuracy (Fig. 7(b)). The fusion model employs multi-head attention (8 heads, 512-d) trained on 1,300 paired samples across 13 categories with AdamW optimization. Results demonstrate that multimodal integration provides complementary information where vision captures global features and tactile reveals local contact details. The confusion matrix (Fig. 7(c)) confirms classification across all objects when both modalities are coordinated.

IV. MODULAR PERCEPTION-DRIVEN GRASPING
To validate that the dual-zone vision-tactile sensing architecture operates effectively across both vacuum and Bernoulli actuation principles, we conduct experiments using two control paradigms: modular perception-driven approach (this section) and learning-based policies (Section V). The modular approach demonstrates that both modes can leverage identical sensing pipelines and control logic with only pneumatic parameter adjustments, operating autonomously using Flexi-Cup’s onboard dual-zone camera. All experiments use Flexi-Cup mounted on a UR3 robot arm (Fig. 8(a)).
A. Modular Control Framework
The modular perception pipeline leverages YOLOv8n for peripheral target detection and ResNet-34 for central tactile verification, demonstrating hardware versatility across classical planning methods. The YOLOv8n detector processes peripheral vision for target localization and workspace boundary detection. When LED illumination is activated, the ResNet-

### 34 segmentation model (pretrained on ImageNet) analyzes

the central tactile imprint to identify contact regions and verify surface flatness. With LED off, a YOLOv8n-seg model

IEEE ROBOTICS AND AUTOMATION LETTERS, VOL. XX, NO. X, XXX 2025 | 5

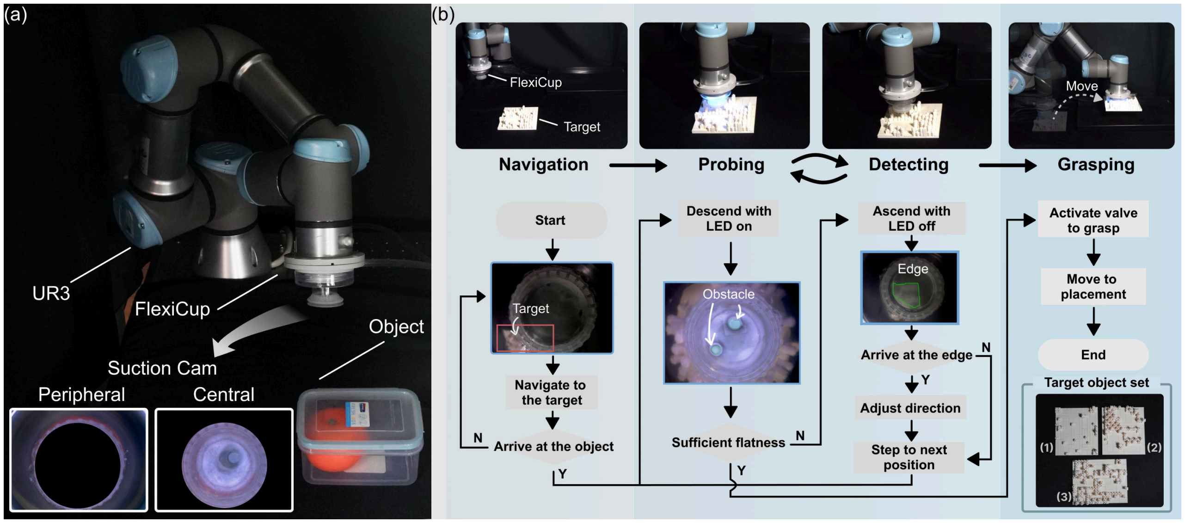
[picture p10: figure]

Fig. 8. Experimental setup and modular control framework for perception-driven grasping. (a) FlexiCup mounted on UR3 robot. (b) Control pipeline integrating YOLOv8 and ResNet-34 for dual-mode validation. Target object set (bottom right): (1)-(3) with 25%, 50%, 75% obstacle coverage.

performs edge detection on the central visual stream to guide
obstacle avoidance during spatial search.
As illustrated in Fig. 8(b), the control pipeline integrates these modules with iterative feedback: peripheral vision detects the target and guides approach; upon arrival, tactile segmentation verifies contact and surface flatness; if unsuitable, the system transitions to vision mode and uses edge detection to guide spatial stepping; finally, valve activation initiates suction and transport.
B. Experimental Configuration
The validation employs identical sensing and control pipelines across both modes, with only bottom housing and pneumatic parameters varying. The three perception modules were trained offline on task-specific datasets: the peripheral vision detector achieved 87.7% mAP50 on 226 images, the tactile segmentation model achieved 98.3% IoU on 18,929 contact samples, and the edge detection module achieved 99.5% mAP50 on 1,954 images, all supporting real-time inference for closed-loop control.
Test materials include custom LEGO boards with 25%, 50%, 75% obstacle coverage. We conduct 30 trials per mode (vacuum and Bernoulli), totaling 180 trials, with success criteria including navigation to target, obstacle-free region identification, stable attachment verified by tactile feedback, and transport without object loss.
C. Results and Analysis
Table II shows vacuum (90.0%) and Bernoulli (86.7%) achieve comparable success rates, validating three key aspects:
(1) Sensing universality—the dual-zone architecture operates effectively across contact-based and non-contact principles; (2) Control portability—the modular perception pipeline requires only pneumatic parameter adjustments without algorithmic

TABLE II
HARDWARE MODALITY VALIDATION: SUCCESS RATES ACROSS PNEUMATIC PRINCIPLES
Test Material | Vacuum | Bernoulli
(1) 25% obstacle coverage | 90.0% | 86.7%
(2) 50% obstacle coverage | 93.3% | 90.0%
(3) 75% obstacle coverage | 86.7% | 83.3%
Mean | 90.0% | 86.7%

modifications; (3) Mechanical modularity—bottom housing reconfiguration maintains full sensing and processing capabilities.
The comparable success rates validate sensing-actuation decoupling: both modes achieve effective manipulation using the shared dual-zone architecture, with performance differences attributable to actuation mechanisms rather than sensing limitations.
Failure cases for both modes occur when the discrete search strategy (1 cm step size) exhaustively traverses the workspace without identifying suitable attachment regions. Success rates peak at moderate obstacle density (mean 91.7%) compared to low and high densities (88.4% and 85.0%), as scattered obstacles can fragment surfaces into regions smaller than the suction cup footprint, affecting both vacuum and Bernoulli modes comparably.
Bernoulli’s slightly lower success rate (86.7% vs 90.0%) stems from reduced adhesion force during the contactless lifting phase: while the shared sensing pipeline successfully identifies suitable regions, the weaker aerodynamic force occasionally fails to maintain grasp on challenging configurations where vacuum’s contact-based adhesion succeeds.
However, Bernoulli provides unique capabilities: a complementary semiconductor wafer handling experiment demonstrates that vacuum-picked wafers exhibit visible contact

IEEE ROBOTICS AND AUTOMATION LETTERS, VOL. XX, NO. X, XXX 2025 | 6

smudging (∼3.5 N peak contact force), while Bernoullipicked wafers remain pristine with near-zero contact force,
confirming contactless handling essential for delicate surfaces (see companion website).

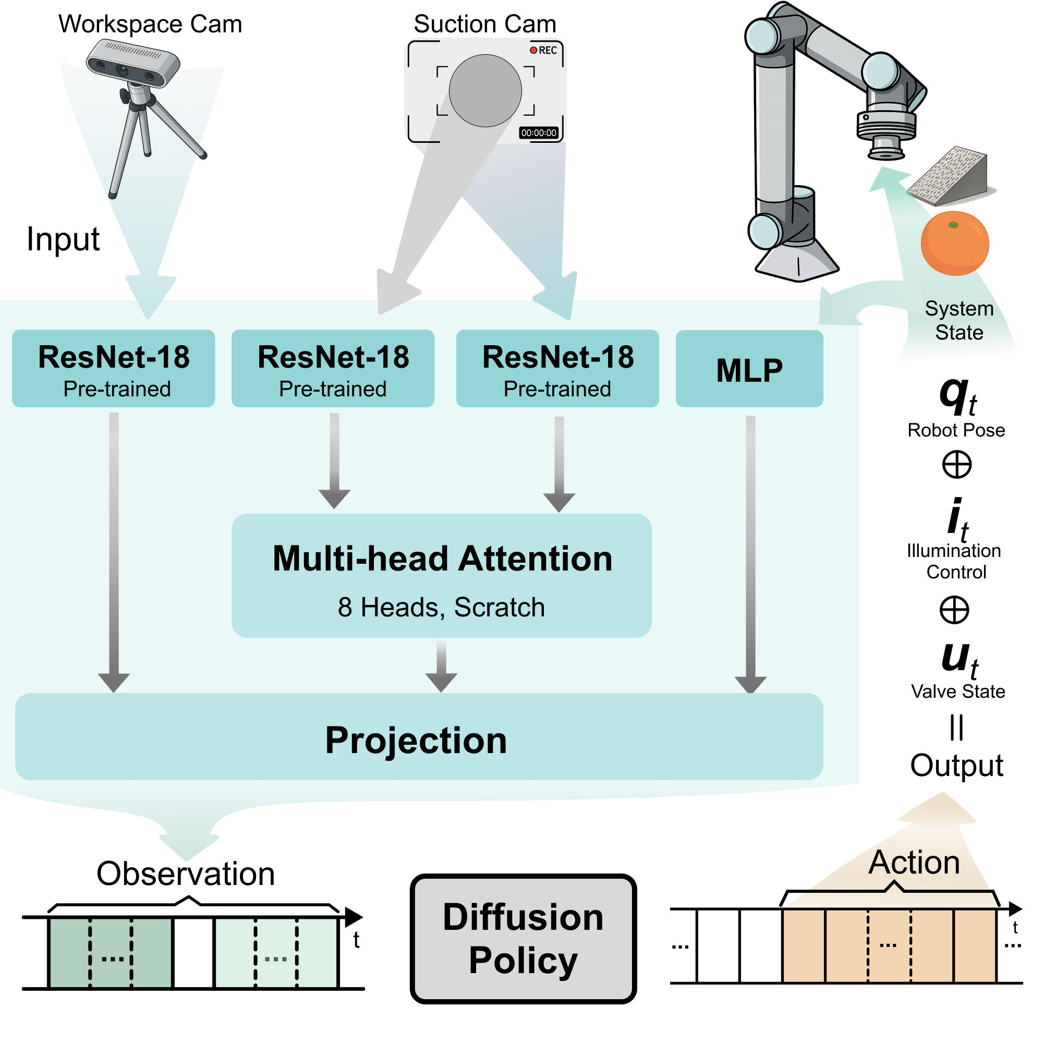
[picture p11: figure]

Fig. 9. Diffusion policy framework processing multimodal observations (workspace camera, peripheral view, central view, system state) through parallel encoders and multi-head attention to generate contact-aware control actions.

V. END-TO-END CONTACT-AWARE MANIPULATION
While the modular perception-driven approach validates hardware reconfigurability, it relies on discrete state transitions and manual threshold tuning. We develop a learning framework based on diffusion policies [28], [29] mapping multimodal observations to action trajectories.
A. Multi-Modal Learning Framework
We adopt the diffusion policy framework for sequential suction operations with vision-tactile modality transitions. The learning experiments utilize vacuum mode (Configuration I) exclusively, as contact-aware policy learning requires continuous tactile feedback from sustained contact and rich membrane deformation. While Section IV demonstrated that the dual-zone sensing architecture operates effectively across both actuation principles, vacuum’s sustained contact provides dense tactile gradients essential for learning finegrained manipulation skills involving contact detection, surface compliance interpretation, and valve timing coordination. In contrast, Bernoulli’s contactless lifting during suction minimizes membrane deformation, providing limited tactile information for learning contact dynamics despite supporting tactile verification during pre-suction positioning.
We extend the framework with multi-head attention to fuse dual-zone observations (Fig. 9), coordinating colocated heterogeneous sensory streams during vision-tactile switching.
B. Multi-Modal Observation Encoding

The system processes observations through specialized encoders. The workspace view I

workspace
t

from the D435 camera provides global scene context, encoded via ImageNet pre-trained ResNet-18 to f

workspace
t | ∈ | R
512. The dual-zone suction camera captures local observations: the central view I

central
t

switches between visual and tactile modes for contact sensing, and the peripheral view I

| | peripheral
t | main-
tains spatial awareness, both encoded through ResNet-18 to f

central
t

, f peripheral
t | ∈ R
512. The system state st ∈ R

8
is
processed through a 2-layer MLP to f
| state
t

C. Feature Integration and Policy Learning

The multi-head attention module (8 heads, 512 dimensions) coordinates the central and peripheral views, correlating contact details with spatial context during approachto-manipulation transitions. Integration proceeds through two stages: workspace features combine with attended suction features, then concatenate with system state to form the complete observation representation.
The diffusion policy generates action trajectories at = [qt, it, ut] controlling robot joints (qt ∈ R
| | 6
), illumination
switching (it), and pneumatic valve (ut). The action chunking mechanism (8-step history, 48-step horizon) generates coordinated sequences for multi-phase operations.
D. Experimental Evaluation

We evaluate two tasks: inclined transport (150 demos) and orange extraction (100 demos), collected via kinesthetic teaching at 30 Hz and downsampled to 10 Hz, with randomized positions, angles, and orientations, and random cropping augmentation (76×76 from 224×224). Inclined transport involves positioning above the surface (7 cm × 5.3 cm × 6 cm), searching for suitable contact regions, adjusting tilt angle guided by tactile feedback to match the inclined surface (5°, 10°, or 15°), verifying contact, and performing secure lifting. Orange extraction consists of transparent cover removal (container: 15 cm × 10.5 cm × 7 cm) in vision mode, realignment above the orange (approximately 6 cm diameter), then tactile-guided grasping with LED-enabled contact detection.
Five configurations (Ours, w/o Multi-Head Attention, w/o Peripheral View, w/o Central View, Workspace Camera Only) and a BC-RNN baseline were trained for 500 epochs with batch size 16 on RTX4090 GPU, with 30 trials per task totaling 300 experiments (Fig. 10). These ablations functionally approximate representative prior architectures: Workspace Camera Only corresponds to conventional vision-guided suction without tactile feedback [10]; w/o Peripheral View approximates single-zone camera-based tactile suction systems [8], [9]; and w/o Central View simulates external-camera-only setups [2] lacking intimate contact observation. Success is defined as completing the full manipulation sequence without object loss, with primary failure modes: (1) object slipping, (2) search budget exhaustion, and (3) phase transition failures. Table III shows the full system achieves 73.3% (inclined transport) and 66.7% (orange extraction). Ablation analysis

IEEE ROBOTICS AND AUTOMATION LETTERS, VOL. XX, NO. X, XXX 2025 | 7

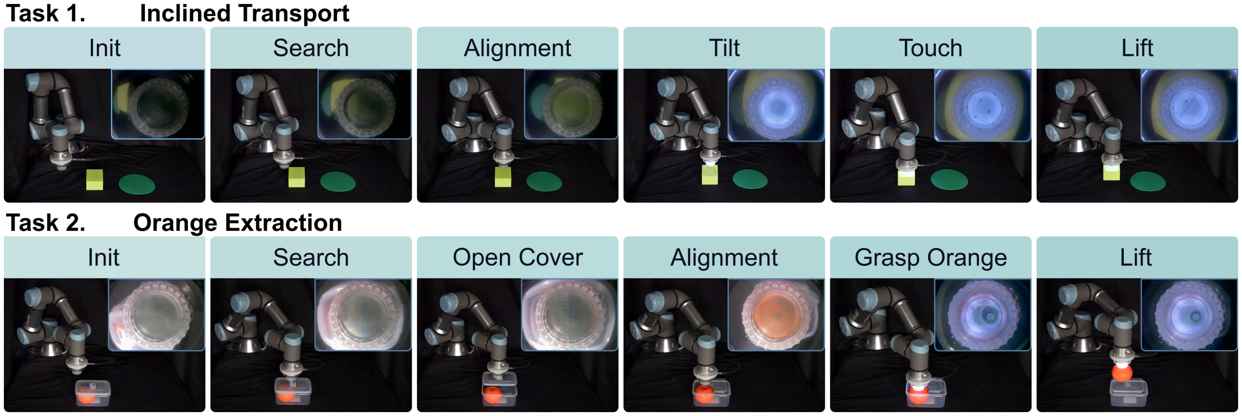
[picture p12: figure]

Fig. 10. Experimental task demonstrations showing inclined transport and orange extraction sequences with multimodal sensing integration.

TABLE III
TASK SUCCESS RATE COMPARISON WITH STATISTICAL ANALYSIS
Configuration | Inclined Transport | Orange Extraction
Ours | 73.3% | 66.7%
w/o Multi-Head Attention | 60.0% | 53.3%
w/o Peripheral View | 43.3% | 36.7%
w/o Central View | 46.7% | 33.3%
Workspace Camera Only | 23.3% | 0.0%
Baseline | Fail | Fail

reveals the central view as critical for contact detection, with its removal reducing performance to 46.7% and 33.3% due to loss of tactile sensing. The peripheral view contributes spatial context essential for approach planning, with its absence degrading performance to 43.3% and 36.7%. Multi-head attention provides 13% improvements by coordinating dual-zone information during vision-tactile transitions. Workspace camera alone achieves only 23.3% and 0.0% success, confirming that intimate sensing is necessary for contact-critical manipulation. The BC-RNN baseline failed both tasks (0% success), frequently becoming stuck or failing to coordinate modality switching—consistent with [28], where recurrent baselines exhibited similar stuck behaviors with multimodal action distributions, confirming the advantage of diffusion policy’s action chunking for coordinated suction manipulation. Failure mode analysis reveals distinct patterns: for configurations lacking peripheral sensing, 60% of failures stem from phase transition difficulties, while for the full system, 70% result from physical constraints rather than perceptual limitations, demonstrating that the multimodal architecture effectively addresses perceptual challenges.

VI. DISCUSSION

Object Limitations. The diameter of the suction cup bounds the manipulable object range. Objects smaller than approximately 15–20 mm fail to establish adequate sealing due to insufficient contact area, while the 41.5 N vacuum force capacity limits practical payload to approximately 2–

### 3 kg under dynamic manipulation. The system requires a

reasonably flat contact region with principal curvature radii exceeding 20–25 mm; highly curved, deeply concave, or highly porous surfaces prevent membrane sealing. Surface roughness exceeding approximately 1–2 mm feature height also causes consistent seal failure.
Wireless Electronics. While pneumatic connections remain, wireless electronics address fragile MIPI CSI cables and complex slip rings by keeping the signal path (CMOS to MCU) onboard. A 30-minute streaming test confirms stable performance: 27.05 FPS, 43 ms latency, compatible with pneumatic seal dynamics (200–500 ms).
Material and Surface Constraints. The PDMS membrane is subject to gradual degradation through repeated contact, particularly with abrasive or sharp-edged objects. Over 500 pick-and-place cycles in our experiments showed no observable degradation, but industrial deployment would require periodic inspection. Additionally, material selection (membrane hardness, tear resistance) and surface preprocessing for porous regions remain important directions for extending the operational envelope.
Dynamic Performance. Dynamic stress tests at 3.0 rad/s joint speed and 3.0 rad/s² acceleration demonstrate stable suction and sensing performance while holding objects with varying mass distributions (orange, water-filled bottle with sloshing dynamics; see companion website).
Sensing and Modality Constraints. High-frequency switching is limited by CMOS stabilization during illumination changes, addressed through (1) finite-state machines switching at task boundaries, or (2) learned switching heuristics from demonstrations. The semi-transparent membrane is also sensitive to ambient lighting; high-intensity internal LEDs overpower external interference in tactile mode, but uncontrolled lighting can occasionally wash out tactile features. Dual-Mode Complementarity. As demonstrated in Section IV, vacuum and Bernoulli modes share identical sensing pipelines but serve complementary domains: vacuum provides sustained contact for tactile-rich learning (Section V), while Bernoulli enables contactless handling for delicate objects (wafer experiment, companion website).

IEEE ROBOTICS AND AUTOMATION LETTERS, VOL. XX, NO. X, XXX 2025 | 8

VII. CONCLUSIONS
This paper presented FlexiCup, a multimodal suction cup with wireless electronics integrating dual-zone vision-tactile sensing through illumination-controlled modality switching. The hardware supports dual suction modes with complementary actuation mechanisms—vacuum for sustained-contact adhesion and Bernoulli for contactless lifting—both sharing the identical dual-zone sensing architecture.
Hardware versatility was validated through dual control paradigms. Modular perception-driven grasping achieves 90.0% (vacuum) and 86.7% (Bernoulli) success rates, confirming that the dual-zone sensing architecture operates effectively across both actuation principles. Performance differences stem from actuation mechanisms rather than sensing limitations, with Bernoulli’s reduced adhesion occasionally leading to object loss while offering unique contactless handling for delicate surfaces, as demonstrated through wafer experiments. Endto-end learning based on diffusion policies achieves 73.3% and 66.7% success on contact-aware manipulation tasks, with ablations confirming 13% improvements from multi-head attention. The integration enables continuous contact-aware manipulation adapting to surface variations without manual threshold engineering.
Current limitations and their implications are discussed in Section VI. The hardware design files, firmware source code, and experimental videos have been made publicly accessible at the companion website. Future work will focus on extending the framework to multi-contact scenarios, investigating computational optimization for embedded hardware, integrated flowswitching mechanisms for online mode reconfiguration, calibrated force sensing to complement the current deformationbased tactile observations, and integrating richer tactile modalities for adaptive suction control.

REFERENCES

[1] T. M. Huh, K. Sanders, M. Danielczuk, M. Li, Y. Chen, K. Goldberg, and
H. S. Stuart, “A multi-chamber smart suction cup for adaptive gripping and haptic exploration,” in 2021 IEEE/RSJ International Conference on Intelligent Robots and Systems (IROS), 2021, pp. 1786–1793.
[2] J. Lee, S. D. Lee, T. M. Huh, and H. S. Stuart, “Haptic search with the smart suction cup on adversarial objects,” IEEE Transactions on Robotics, vol. 40, pp. 226–239, 2024.
[3] P. Davis, B. Gray, and K. Caldwell, “An end effector based on the Bernoulli principle for handling sliced fruit and vegetables,” Robotics and Computer-Integrated Manufacturing, vol. 24, no. 2, pp. 249–257, 2008.
[4] S. Liu, X. Wang, Y. Zhang, and H. Chen, “Design and tests of a noncontact Bernoulli gripper for rough-surfaced and fragile objects gripping,” Engineering Science and Technology, an International Journal, vol. 23, no. 4, pp. 729–738, 2020.
[5] Y. Yoo, J. Eom, M. J. Park, and K.-J. Cho, “Compliant suction gripper with seamless deployment and retraction for robust picking against depth and tilt errors,” IEEE Robotics and Automation Letters, vol. 8, no. 3, pp. 1492–1499, 2023.
[6] S. Doi, H. Koga, T. Seki, and Y. Okuno, “Novel proximity sensor for realizing tactile sense in suction cups,” in 2020 IEEE International Conference on Robotics and Automation (ICRA), 2020, pp. 638–643.
[7] S. Aoyagi, M. Suzuki, T. Morita, T. Takahashi, and H. Takise, “Bellows suction cup equipped with force sensing ability by direct coating thinfilm resistor for vacuum type robotic hand,” IEEE/ASME Transactions on Mechatronics, vol. 25, no. 5, pp. 2501–2512, Oct. 2020.
[8] S. van Veggel, M. Wiertlewski, E. L. Doubrovski, A. Kooijman, B. Mazzolai, and R. B. N. Scharff, “Optoelectronically innervated suction cup inspired by the octopus,” Advanced Intelligent Systems, vol. 7, no. 4, p. 2400544, 2025.
[9] R. Yuan, J. Ren, Z. Peng, F. Chen, and G. Gu, “SuckTac: Camera-based tactile sucker for unstructured surface perception and interaction,” arXiv preprint arXiv:2511.02294, 2025.
[10] C. Wang, J. van Baar, C. Mitash, S. Li, D. Randle, W. Wang, S. Sontakke, K. E. Bekris, and K. Katyal, “Demonstrating multi-suction item picking at scale via multi-modal learning of pick success,” arXiv preprint arXiv:2506.10359, 2025.
[11] Z. Zhao, Y. Liu, W. Chen, and K. Zhang, “PolyTouch: A robust multi-modal tactile sensor for contact-rich manipulation using tactilediffusion,” in 2025 IEEE International Conference on Robotics and Automation (ICRA), 2025.
[12] J. Jones, O. Mees, C. Sferrazza, K. Stachowicz, P. Abbeel, and S. Levine, “Beyond Sight: Finetuning generalist robot policies with heterogeneous sensors via language grounding,” arXiv preprint arXiv:2501.04693, 2025.
[13] Z. Zhao, W. Li, Y. Li, T. Liu, B. Li, M. Wang, K. Du, H. Liu, Y. Zhu, Q. Wang, K. Althoefer, and S.-C. Zhu, “Embedding high-resolution touch across robotic hands enables adaptive human-like grasping,” Nature Machine Intelligence, pp. 1–12, 2025.
[14] P. Lin, Y. Huang, W. Li, J. Ma, C. Xiao, and Z. Jiao, “PP-Tac: Paper picking using tactile feedback in dexterous robotic hands,” arXiv preprint arXiv:2504.16649, 2025.
[15] M. Wang, Y. Zhou, J. Luo, and S. Wang, “Large-scale deployment of vision-based tactile sensors on multi-fingered grippers,” arXiv preprint arXiv:2405.08959, 2024.
[16] E. Del Bianco, D. Torielli, F. Rollo, D. Gasperini, A. Laurenzi, L. Baccelliere, L. Muratore, M. Roveri, and N. G. Tsagarakis, “A high-force gripper with embedded multimodal sensing for powerful and perception driven grasping,” in 2024 IEEE-RAS 23rd International Conference on Humanoid Robots (Humanoids), 2024, pp. 149–156.
[17] E. Shahabi, F. Visentin, A. Mondini, and B. Mazzolai, “Octopus-inspired suction cups with embedded strain sensors for object recognition,” Advanced Intelligent Systems, vol. 5, no. 2, p. 2200201, 2023.
[18] T. Yue, C. Lu, K. Tang, Q. Qi, Z. Lu, L. Y. Lee, H. Bloomfield-Gadelha, and J. Rossiter, “Embodying soft robots with octopus-inspired ˆ hierarchical suction intelligence,” Science Robotics, vol. 10, no. 102, p. eadr4264, 2025.
[19] N. Jang, M. W. Lee, and D. Hwang, “A suction-based peripheral nerve gripper capable of controlling the suction force,” IEEE/ASME Transactions on Mechatronics, vol. 26, no. 4, pp. 1867–1876, Aug. 2021.
[20] T. Shiratori, Y. Kanazawa, J. Sakamoto, T. Takahashi, M. Suzuki, and
S. Aoyagi, “Development of a vision-based tactile sensor with micro suction cups,” Sensors and Actuators A: Physical, vol. 371, p. 115276, 2024.
[21] W. Yuan, S. Dong, and E. H. Adelson, “GelSight: High-resolution robot tactile sensors for estimating geometry and force,” Sensors, vol. 17, no. 12, p. 2762, 2017.
[22] M. Lambeta, P.-W. Chou, S. Tian, B. Yang, B. Maloon, V. R. Most,
D. Stroud, R. Santos, A. Byagowi, G. Kammerer, D. Jayaraman, and
R. Calandra, “DIGIT: A novel design for a low-cost compact high-resolution tactile sensor with application to in-hand manipulation,” IEEE Robotics and Automation Letters, vol. 5, no. 3, pp. 3838–3845, 2020.
[23] D. Ma, E. Donlon, S. Dong, and A. Rodriguez, “Dense tactile force estimation using GelSlim and inverse FEM,” in 2019 International Conference on Robotics and Automation (ICRA), 2019, pp. 5418–5424.
[24] T. Motoda, T. Kitamura, R. Hanai, and Y. Domae, “SuctionPrompt: Visual-assisted robotic picking with a suction cup using vision-language models and facile hardware design,” arXiv preprint arXiv:2410.23640, 2024.
[25] A. Patel, D. Kumar, S. Lee, and J. Brown, “Deep reinforcement learning for tactile robotics: learning to type on a braille keyboard,” in 2024 IEEE International Conference on Robotics and Automation (ICRA), 2024, pp. 5678–5685.
[26] X. Song, Y. Li, Y. Zhang, Y. Liu, and L. Jiang, “An overview of learning-based dexterous grasping: recent advances and future directions,” Artificial Intelligence Review, vol. 58, no. 10, pp. 1–44, 2025.
[27] S. An, Z. Meng, C. Tang, Y. Zhou, T. Liu, F. Ding, S. Zhang, Y. Mu,
R. Song, W. Zhang, Z. Hou, and H. Zhang, “Dexterous manipulation through imitation learning: A survey,” arXiv preprint arXiv:2504.03515, 2025.
[28] C. Chi, Z. Xu, S. Feng, E. Cousineau, Y. Du, B. Burchfiel, R. Tedrake, and S. Song, “Diffusion Policy: Visuomotor policy learning via action diffusion,” The International Journal of Robotics Research, 2023.
[29] Z. Xue, S. Deng, Z. Chen, Y. Wang, Z. Yuan, and H. Xu, “DemoGen: Synthetic demonstration generation for data-efficient visuomotor policy learning,” arXiv preprint arXiv:2506.08680, 2025.

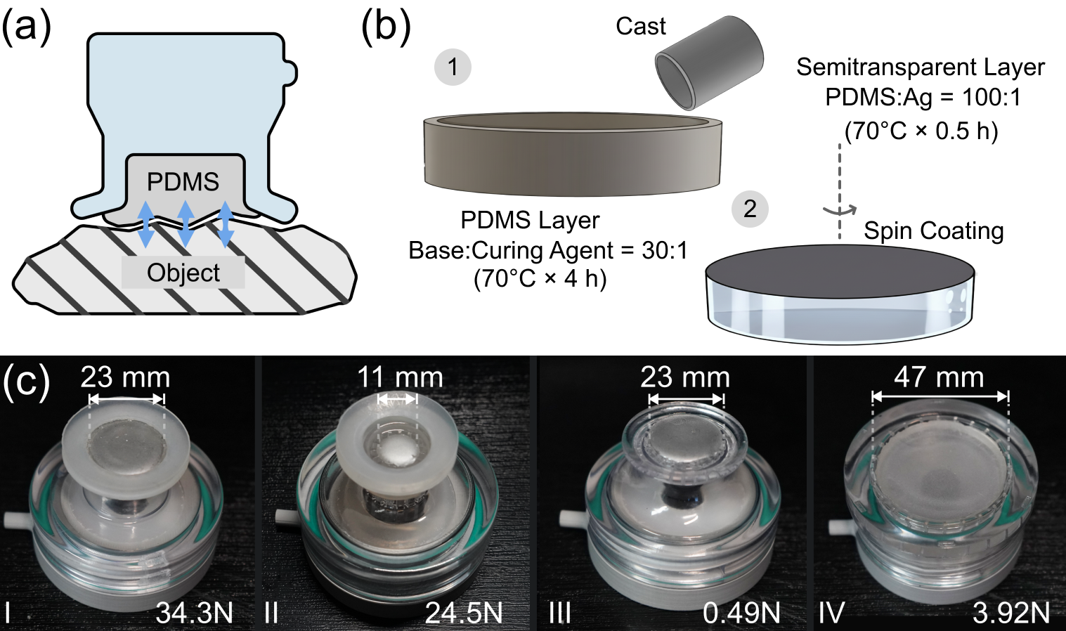
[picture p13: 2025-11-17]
static/images/image/FigPDMS Membrane Design.png

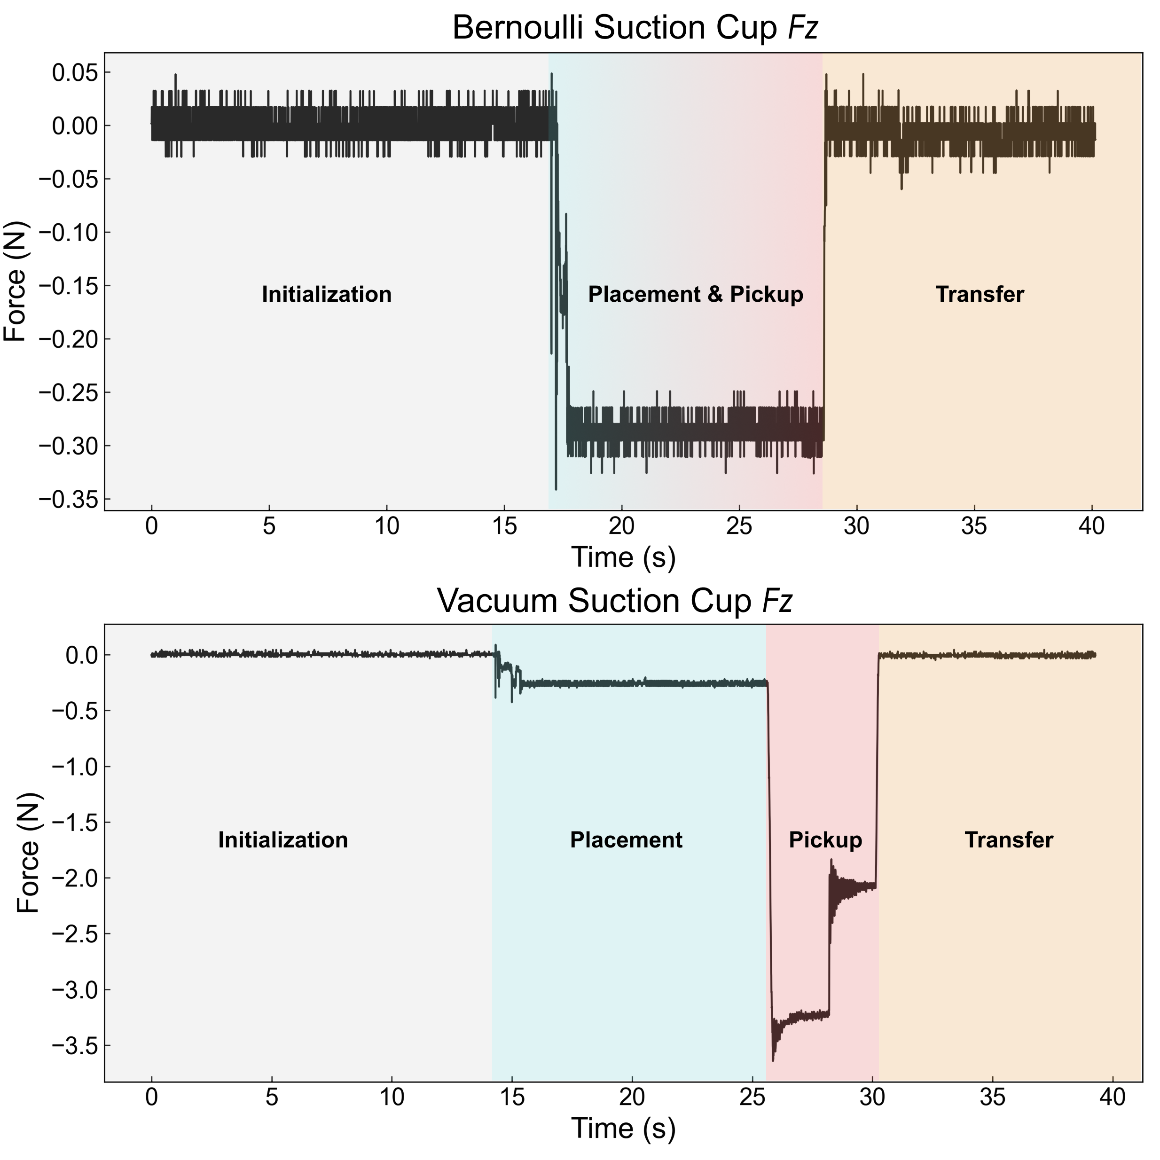
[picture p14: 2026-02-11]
static/images/image/ResWaferForce.png

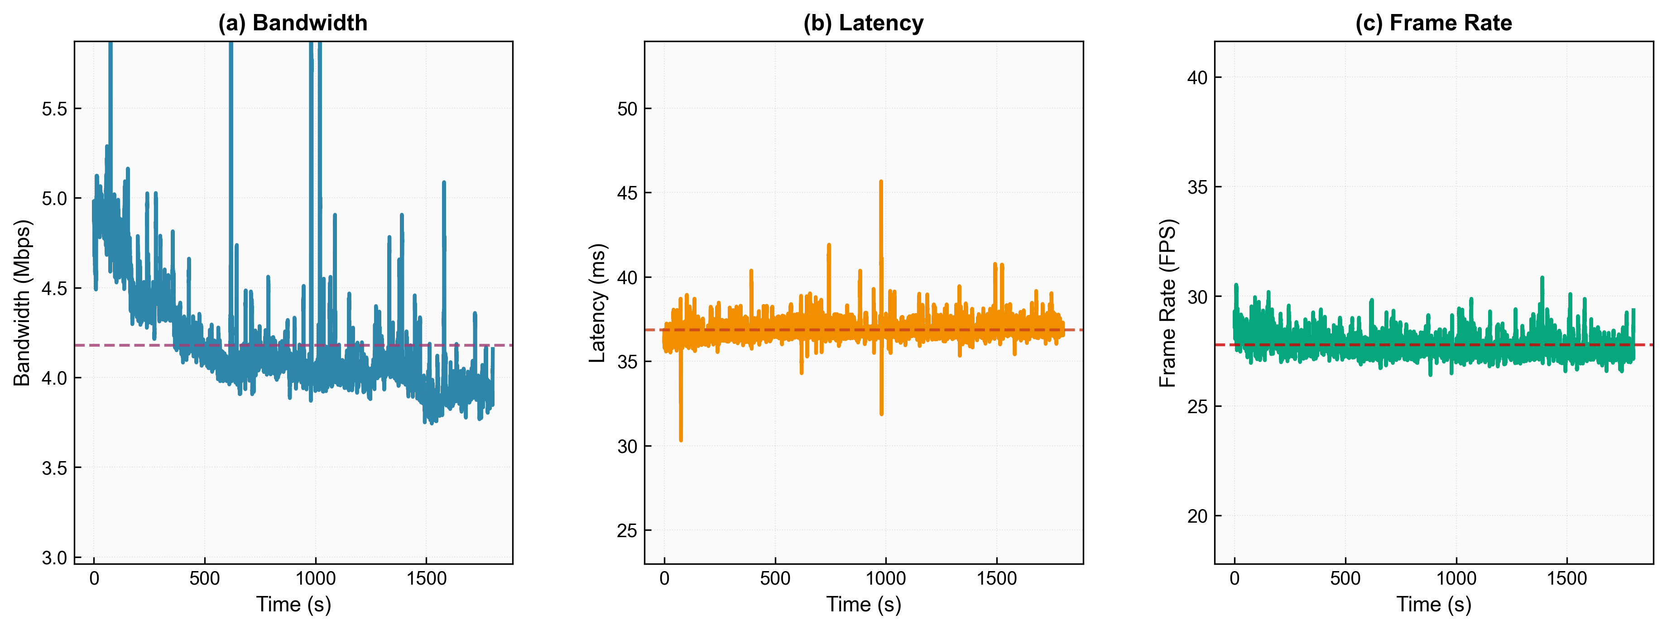
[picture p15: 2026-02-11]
static/images/image/ResComLatency.png

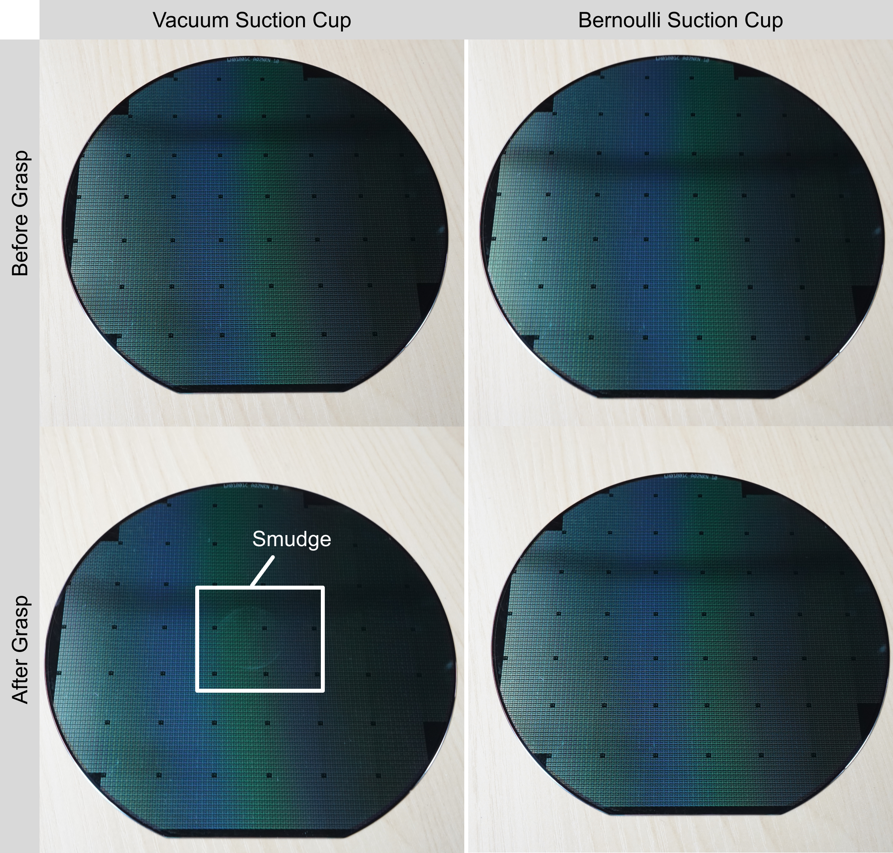
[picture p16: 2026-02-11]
static/images/image/ResWaferCompare.png

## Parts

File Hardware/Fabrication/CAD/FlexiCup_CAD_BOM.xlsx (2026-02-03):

Item | Component Name | Type | Material / Model | Fabrication / Specification | Source / Notes
1 | PDMS Layer | Custom | PDMS (Silicone Elastomer) | Mass ratio 30:1; cured at 70°C for 4 h | https://item.taobao.com/item.htm?id=771400708673
2 | Semitransparent Layer | Custom | Ag/PDMS composite | Ag:PDMS 100:1; cured at 70°C for 0.5 h | https://item.taobao.com/item.htm?id=639664267249
3 | Sealing Skirt | Custom | Silicone rubber | Laser-cut from commercial silicone suction cup (edge section) | https://item.taobao.com/item.htm?id=44450088023
4 | Light Diffuser | Commercial + Laser cut | Plastic frosted diffuser sheet | Laser-cut to shape | https://detail.tmall.com/item.htm?id=815395281668
5 | Camera | Commercial | OV5640, DVP interface | CMOS image sensor module | https://item.taobao.com/item.htm?id=740340174798
6 | Suction Cup Bottom | Custom | Transparent photocured resin | 3D printed | Custom fabricated
7 | Battery | Commercial | 3.7 V 300 mAh LiPo | Rechargeable lithium polymer battery | https://item.taobao.com/item.htm?id=528235852444
8 | O-Ring | Commercial | FKM (Fluororubber) | Airtight sealing | https://detail.tmall.com/item.htm?id=20666871267
9 | Charging Coil | Commercial | Inductive coil | 12.5 µH | https://item.taobao.com/item.htm?id=659955785738
10 | Suction Cup Top | Custom | PLA | 3D printed | Custom fabricated
11 | PCB Assembly | Custom | FR-4 PCB + SMT | PCB fabrication & SMT assembly | JLCPCB

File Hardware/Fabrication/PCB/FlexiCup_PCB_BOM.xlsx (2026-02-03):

No. | Quantity | Comment | Designator | Footprint | Value | Manufacturer Part | Manufacturer | Supplier Part | Supplier
1 | 3 | 10uF | C1,C15,C19 | R0603 | 10uF | CL10A106KP8NNNC | SAMSUNG(三星) | C19702 | LCSC
2 | 2 | 4.7uF | C2,C18 | R0603 | 4.7uF | CL10A475KO8NNNC | SAMSUNG(三星) | C19666 | LCSC
3 | 4 | 1uF | C3,C13,C20,C28 | R0603 | 1uF | CL05A105KA5NQNC | SAMSUNG(三星) | C52923 | LCSC
4 | 4 | 100nF | C4,C23,C24,C27 | R0603 | 100nF | CL05B104KO5NNNC | SAMSUNG(三星) | C1525 | LCSC
5 | 2 | 100nF | C5,C16 | R0603 | 100nF | CL05B104KB54PNC | SAMSUNG(三星) | C307331 | LCSC
6 | 3 | 47nF | C6,C7,C10 | R0603 | 47nF | CC0402KRX7R9BB473 | YAGEO(国巨) | C272875 | LCSC
7 | 1 | 33nF | C8 | R0603 | 33nF | 0402F333M500NT | FH(风华) | C1585 | LCSC
8 | 1 | 2.2nF | C9 | R0603 | 2.2nF | 0402B222K500NT | FH(风华) | C1531 | LCSC
9 | 1 | 1uF | C11 | R0603 | 1uF | CL05B104KO5NNNC | SAMSUNG(三星) |  | LCSC
10 | 1 | 10uF | C12 | R0603 | 10uF | CL05B104KO5NNNC | SAMSUNG(三星) |  | LCSC
11 | 2 | 10uF | C14,C29 | R0603 | 10uF | CL05A106MQ5NUNC | SAMSUNG(三星) | C15525 | LCSC
12 | 1 | 100uF | C17 | CAP-SMD_L3.5-W2.8 | 100uF | F931A107KBAAHA | Kyocera AVX | C304232 | LCSC
13 | 1 | 10nF | C21 | R0603 | 10nF | CL05B103KB5NNNC | SAMSUNG(三星) | C15195 | LCSC
14 | 3 | 4.7uF | C22,C25,C26 | R0603 | 4.7uF | CL05A475MP5NRNC | SAMSUNG(三星) | C23733 | LCSC
15 | 2 | 12pF | C30,C31 | R0603 | 12pF | 0402CG120J500NT | FH(风华) | C1547 | LCSC
16 | 1 | SS34 | D1 | SMA_L4.3-W2.5-LS5.0-RD |  | SS34 | TWGMC(台湾迪嘉) | C727060 | LCSC
17 | 1 | HC-FPC-05-09-24RLTAG | FPC1 | FPC-SMD_24P-P0.50_HC-FPC-05-09-24RLTAG |  | HC-FPC-05-09-24RLTAG | HCTL(华灿天禄) | C5213757 | LCSC
18 | 5 | 2.54-1*1P针 | H1,H2,H3,H4,H5 | HDR-TH_1P-P2.54-V-M |  | 2.54-1*1P针 | BOOMELE(博穆精密) | C81276 | LCSC
19 | 1 | CA-C03 | INA1 | ANT-SMD_CA-C03 |  | CA-C03 |  | C2838842 | LCSC
20 | 2 | 0ou | L1,L3 | R0603 | 0ou | LQG15HS3N3B02D | muRata(村田) |  | LCSC
21 | 1 | 3nH | L2 | R0603 | 3nH | LQG15HS3N0S02D | muRata(村田) | C19898 | LCSC
22 | 1 | 2nH | L4 | R0603 | 2nH | LQG15HS2N0S02D | muRata(村田) | C18216 | LCSC
23 | 2 | KT-0603R | LED1,LED2 | LED0603-RD |  | KT-0603R | KENTO | C2286 | LCSC
24 | 6 | WS2812B-4020 | LED9,LED10,LED11,LED12,LED13,LED14 | LED-SMD_WS2812B-4020 |  | WS2812B-4020 | worldsemi | C965557 | LCSC
25 | 1 | AMS1117-3.3V | Q1 | SOT-89-3_L4.5-W2.5-P1.50-LS4.2-BR |  | AMS1117-3.3V | MSKSEMI(美森科) | C5120796 | LCSC
26 | 1 | DMG2305UX-7 | Q2 | SOT-23-3_L2.9-W1.3-P1.90-LS2.4-BR |  | DMG2305UX-7 | DIODES(美台) | C150470 | LCSC
27 | 1 | 220Ω | R1 | R0805 | 220Ω | 0805W8F2200T5E | UNI-ROYAL(厚声) | C17557 | LCSC
28 | 2 | 1kΩ | R2,R3 | R0603 | 1kΩ | 0603WAF1001T5E | UNI-ROYAL(厚声) | C21190 | LCSC
29 | 1 | 2kΩ | R4 | R0603 | 2kΩ | 0603WAF2001T5E | UNI-ROYAL(厚声) | C22975 | LCSC
30 | 1 | 1MΩ | R5 | R0603 | 1MΩ | 0603WAF1004T5E | UNI-ROYAL(厚声) | C22935 | LCSC
31 | 2 | 10kΩ | R6,R8 | R0603 | 10kΩ | 0402WGF1002TCE | UNI-ROYAL(厚声) | C25744 | LCSC
32 | 2 | 10K | R10,R11 | R0603 | 10K
33 | 4 | M2螺丝 | SCREW1,SCREW2,SCREW3,SCREW4 | M2螺丝
34 | 1 | MINI MSK12CO2 | SW1 | SW-SMD_MSK12CO2 |  | MINI MSK12CO2 | SHOU HAN(首韩) | C2681570 | LCSC
35 | 1 | VRD1528MLX | U1 | LLP-6_L2.0-W1.8-P0.50-BL-EP |  | VRD1528MLX | AnaSem(安纳森) | C697912 | LCSC
36 | 1 | NU1680 | U2 | QFN-16_L3.0-W3.0-P0.50-TL-EP1.9 |  | NU1680 |  | C9900015597 | LCSC
37 | 1 | TP4054 | U3 | TSOT-23-5_L2.9-W1.6-P0.95-LS2.8-BR |  | TP4054 | UMW(友台半导体) | C668215 | LCSC
38 | 1 | ESP32-S3R8 | U4 | QFN-56_L7.0-W7.0-P0.40-TL-EP4.0 |  | ESP32-S3R8 | ESPRESSIF(乐鑫) | C2913194 | LCSC
39 | 1 | BLM15BA050SN1D | U5 | R0603 |  | BLM15BA050SN1D | muRata(村田) | C160969 | LCSC
40 | 1 | W25Q128JVPIQ | U6 | WSON-8_L6.0-W5.0-P1.27-BL-EP |  | W25Q128JVPIQ | WINBOND(华邦) | C190862 | LCSC
41 | 1 | 40MHz | X1 | CRYSTAL-SMD_4P-L2.5-W2.0-BL | 40MHz | TXM40M0004252HBCEO00T | YJX(雅晶鑫) | C284176 | LCSC

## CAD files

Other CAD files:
Hardware/Fabrication/CAD/suction cup bottom II.STEP
Hardware/Fabrication/CAD/suction cup bottom I.STEP
Hardware/Fabrication/CAD/suction cup bottom III.STEP
Hardware/Fabrication/CAD/suction cup bottom IV.STEP
Hardware/Fabrication/CAD/FlexiCup_Vacuum.STEP
Hardware/Fabrication/CAD/FlexiCup_Bernoulli .STEP
Hardware/Fabrication/CAD/suction cup top.STEP

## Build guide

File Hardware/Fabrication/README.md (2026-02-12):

# FlexiCup Fabrication Design

This directory contains the fabrication design files for the FlexiCup system.

## Directory Structure

- **CAD/**: 3D CAD models and mechanical design files (STEP format)
- **PCB/**: PCB schematics, layout, BOM, and Gerber manufacturing files

## CAD Files

The CAD directory contains STEP files for:
- `FlexiCup_Vacuum.STEP`: Complete vacuum mode assembly
- `FlexiCup_Bernoulli.STEP`: Complete Bernoulli mode assembly
- `suction cup top.STEP`: Top housing with camera and electronics
- `suction cup bottom I–IV.STEP`: Four interchangeable bottom configurations
  - I & II: Vacuum mode (varying membrane diameters for deformable objects and tactile sensitivity)
  - III & IV: Bernoulli mode
- `FlexiCup_CAD_BOM.xlsx`: Complete mechanical Bill of Materials

## PCB Design

The PCB directory includes:
- `FlexiCup_Schematic.pdf`: Circuit schematic (ESP32-S3, OV5640 interface, WS2812 LED driver, power management, wireless charging)
- `FlexiCup_PCB.pdf`: PCB layout
- `FlexiCup_PCB_BOM.xlsx`: Electronic components BOM
- `Gerber_PCB.zip`: Gerber files for direct PCB manufacturing

## Manufacturing

All design files are ready for manufacturing. The top housing can be 3D printed (PLA, FDM, 0.2 mm layer height, 20–30% infill). The PDMS membrane requires a dual-layer fabrication process (30:1 PDMS base + Ag:PDMS 100:1 reflective layer). See `TUTORIAL.pdf` in the repository root for detailed fabrication instructions.

**Note**: Large CAD files (*.STEP) are managed with Git LFS.

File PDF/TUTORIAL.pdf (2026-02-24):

FlexiCup Fabrication and Deployment Guide | 1

## FlexiCup Fabrication and Deployment Guide

### Overview

This guide provides comprehensive instructions for fabricating, assembling, and deploying the FlexiCup system—a wireless multimodal suction cup with dual-zone vision-tactile sensing. The system supports both vacuum and Bernoulli actuation modes through modular mechanical design while maintaining the identical sensing architecture.

### Contents

1 Hardware Fabrication | 2
2 Firmware Development | 5
3 Learning Pipeline | 6
4 Pneumatic System Setup | 7
5 System Integration and Testing | 8

FlexiCup Fabrication and Deployment Guide | 2
6 Troubleshooting | 9
7 Future Improvements | 9
8 Conclusion | 10

FlexiCup Fabrication and Deployment Guide | 3

### Hardware Fabrication

Bill of Materials (BOM)

Complete mechanical component specifications and sourcing information are provided in:
- CAD BOM: Hardware/Fabrication/CAD/FlexiCup_CAD_BOM.xlsx
- PCB BOM: Hardware/Fabrication/PCB/FlexiCup_PCB_BOM.xlsx
All materials are commercially available or can be fabricated using standard manufacturing processes.

PDMS Membrane Fabrication

The dual-layer PDMS membrane provides both tactile sensing and pneumatic sealing.

Base Layer (Structural Compliance)

- Material: PDMS (Sylgard 184 or equivalent)
- Mixing ratio: 30:1 (base:curing agent by mass)
- Curing conditions: 70 ◦C for 4 hours
- Function: Provides mechanical compliance for capturing surface contact details

Semitransparent Sensing Layer (Optical Interface)

- Material: Silver powder mixed with PDMS
- Mixing ratio: Ag:PDMS = 100:1 (by mass)
- Application method: Spin coating at 1000 rpm onto cured base layer
- Curing conditions: 70 ◦C for 0.5 hours
- Function: Creates reflective surface for photometric tactile imaging while maintaining ambient light transmission
Critical Note: The silver-PDMS ratio and spin coating parameters have been extensively optimized. Deviations may compromise dual-zone sensing performance by affecting light transmission or tactile contrast.
Alternative Materials: For cost-sensitive applications, the base PDMS can be substituted with silicone elastomers (e.g., Smooth-On Ecoflex series) with comparable Shore hardness.

Sealing Skirt

The sealing skirt is critical for pneumatic performance in both vacuum and Bernoulli modes.

Fabrication Method

- Source material: Commercial silicone suction cups
- Process: Laser cutting along designated edge profiles
- Equipment: CO2 laser cutter with adjustable power settings
- Parameters: High power setting with continuous ventilation
Safety Warning: Laser cutting of silicone generates hazardous fumes. Ensure adequate ventilation, fume extraction, and thermal management. Use appropriate personal protective equipment (PPE).

Light Diffuser

The light diffuser ensures uniform LED illumination for tactile imaging while resisting pneumatic deformation.
- Material: Rigid transparent plastic sheet (polycarbonate or acrylic)

FlexiCup Fabrication and Deployment Guide | 4
- Thickness: 0.5–1.0 mm
- Function: Distributes LED light uniformly across the membrane while maintaining structural rigidity under airflow
Alternative Materials: Any transparent rigid material with sufficient stiffness can be substituted. Material selection should prioritize optical clarity and resistance to pneumatic pressure.

Camera Module

The optical sensing system requires a wide field-of-view camera for dual-zone perception.
- Sensor: OV5640 (or compatible)
- Lens: 180◦ fisheye (preferred) or 160◦ wide-angle
- Resolution: 640 × 480 pixels at 30 FPS
- Interface: Compatible with ESP32-S3 camera interface
Known Limitations: The OV5640 is an older sensor with moderate resolution, thermal generation during continuous operation, and occasional stability issues.
Upgrade Opportunity: Adapting newer camera modules (e.g., OV5647, IMX219) and developing ESP32 low-level drivers would significantly improve system performance.

Suction Cup Top Housing

- Material: PLA (standard 3D printing filament)
- Process: Fused deposition modeling (FDM) 3D printing
- Layer height: 0.2 mm recommended
- Infill: 20–30% for adequate structural strength
Material Flexibility: Standard PLA from common desktop 3D printers provides sufficient mechanical properties. Alternative materials (PETG, ABS) can be used if preferred.

Battery and Power System

The wireless electronics require onboard power with optional wired backup for extended data collection.

Battery Specifications

- Type: Lithium polymer (LiPo)
- Voltage: 3.7 V nominal
- Capacity: 300 mAh (standard configuration)
- Runtime: Approximately 30 minutes continuous operation
- Charging: Wireless charging at 200 mA (2-hour charge time)
Capacity Scaling: Battery capacity is limited only by the internal volume of the suction cup top housing. Higher-capacity batteries can be used for extended operation.

Wired Power Option

For long-duration robot learning tasks requiring continuous data collection, a wired power supply
option is provided. Refer to the PCB schematic (Hardware/Fabrication/PCB/FlexiCup_Schematic.pdf) for connection details.

Sealing Components

- Material: Fluoroelastomer (FKM) O-ring for chemical resistance
- Function: Provides pneumatic seal between top and bottom housings
- Sizing: Must fit the groove in the suction cup top housing

FlexiCup Fabrication and Deployment Guide | 5

Note: While custom O-ring dimensions would optimize sealing performance, any standard O-ring that fits the housing groove provides adequate sealing for both vacuum and Bernoulli modes.

Wireless Charging System

- Charging coil: 12.5 µH inductance
- Charging current: 200 mA
- Charging time: Approximately 2 hours for 300 mAh battery
- Circuit: Standard Qi-compatible wireless charging receiver
Implementation: Numerous open-source wireless charging circuits are available online. The system uses a standard implementation without significant modifications.

PCB Assembly

Key Components

- Microcontroller: ESP32-S3 (dual-core, Wi-Fi enabled)
- Camera interface: Compatible with OV5640
- LED driver: WS2812 addressable RGB LEDs
- Power management: Battery charging and regulation circuitry
- Antenna: PCB trace antenna

PCB Antenna Design

The PCB antenna design is critical for reliable wireless operation. Refer to ESP32-S3 hardware
design guidelines for antenna layout requirements, including ground plane clearance, impedance matching, and keep-out zones.
Fabrication Files: Complete Gerber files are provided in Hardware/Fabrication/PCB/Gerber_PCB.zip for direct PCB manufacturing.

LED Light Source

- Type: WS2812 addressable RGB LEDs
- Control: Digital control via ESP32-S3
- Function: Provides internal illumination for tactile imaging
Advanced Capabilities: The WS2812 LEDs support full RGB color control and dynamic patterns. This capability could enable additional visuotactile functionalities such as structured light patterns for 3D surface reconstruction and color-coded illumination for multi-modal sensing.

Assembly Instructions

Assembly Sequence

### 1. PCB Mounting — Secure PCB to suction cup top housing using M2.5 screws. Ensure

proper alignment of camera module with optical aperture.

### 2. Battery and Antenna Installation — Position battery in the space between PCB and

top housing. Route antenna cable and secure in designated cavity. Ensure no interference with pneumatic airways.
3. Light Diffuser Installation — Insert light diffuser into the outlet of the suction cup top. Secure via friction fit (no adhesive required). Verify uniform spacing around perimeter.

### 4. PDMS Membrane Installation — Place dual-layer PDMS membrane in the central

groove of bottom housing. Ensure complete seating without wrinkles or air gaps.
5. Sealing Skirt Attachment — Attach silicone sealing skirt to bottom housing perimeter. Verify complete contact around circumference.

FlexiCup Fabrication and Deployment Guide | 6

### 6. Housing Assembly — Apply O-ring to groove in top housing. Thread bottom housing

onto top housing. Tighten until firm resistance (do not overtighten).

### 7. Pneumatic Connection — Connect appropriate pneumatic source (vacuum pump or air

compressor). Verify airtight connection at pneumatic interface.

Assembly Notes

Structural Considerations: While the assembly method may appear improvised, extensive testing has validated its effectiveness. The friction-fit light diffuser provides adequate retention while allowing easy disassembly for maintenance.
Interesting Phenomenon: During testing, we observed that the light diffuser appears to enhance suction force in vacuum mode. We hypothesize this may result from the Bernoulli effect: as airflow passes through gaps between the light diffuser and housing components, flow acceleration reduces local pressure, contributing additional suction force (analogous to the Venturi effect). This phenomenon appears only in vacuum mode, not in Bernoulli mode, suggesting complex fluid–structure interactions.

### Firmware Development

Development Environment

The firmware is developed using ESP-IDF (Espressif IoT Development Framework).
- ESP-IDF Version: 5.0.2
- Toolchain: Xtensa ESP32-S3 toolchain
- Build system: CMake-based build system
- Source code: Hardware/Firmware/ESPCAM/

Configuration

Before compilation, modify the following parameters in the source code:

Network Configuration

// WiFi credentials
#define WIFI_SSID "your_network_name" #define WIFI_PASSWORD "your_password"

// UDP communication
#define UDP_TARGET_IP "192.168.1.xxx" #define UDP_PORT 8888

Camera Configuration

// Camera model and resolution
#define CAMERA_MODEL CAMERA_MODEL_ESP32S3_EYE #define FRAME_SIZE FRAMESIZE_VGA // 640x480

#define JPEG_QUALITY 12

Additional parameters (frame rate, exposure, gain) can be customized based on application requirements.

FlexiCup Fabrication and Deployment Guide | 7

Compilation and Flashing

Build Process

cd Hardware/Firmware/ESPCAM idf.py build

Flashing Hardware Setup

Due to space constraints, programming pads are provided on the PCB back instead of a dedicated connector.
Required Connections (USB-to-TTL module):
- TX (module) → RX (ESP32)
- RX (module) → TX (ESP32)
- GND (module) → GND (ESP32)
- 3.3V (module) → 3.3V (ESP32) [optional, can use battery power]
Boot Mode Selection Pads: RST (reset signal), BOOT0 (boot mode selection).

Flashing Procedure

### 1. Enter Download Mode:

(a) Connect BOOT0 pad to GND
(b) Connect RST pad to GND (pull low)
(c) Release RST (allow to float high)
(d) Release BOOT0 — ESP32 enters download mode

### 2. Flash Firmware:

idf.py -p /dev/ttyUSB0 flash

### 3. Monitor Serial Output (optional):

idf.py -p /dev/ttyUSB0 monitor

### 4. Reset to Run Mode: Briefly connect RST to GND and release. The device will boot

into normal operation mode.

Wireless Operation

After successful flashing, the device operates wirelessly:
- Connects to configured Wi-Fi network
- Streams camera images via UDP at 30 FPS
- Receives control commands for LED and valve actuation
- Provides approximately 30 minutes of battery operation

### Learning Pipeline

Overview

The complete learning pipeline for diffusion-based end-to-end manipulation is provided in the repository. The system supports both modular perception-driven grasping and learning-based policies.

FlexiCup Fabrication and Deployment Guide | 8

Data Collection

Current Implementation: Keyboard Teleoperation

The provided data collection script uses keyboard teleoperation for demonstration collection. However, this method produces jerky, discontinuous motions and is sensitive to movement step size parameters, making it suboptimal for learning smooth manipulation policies.

Recommended Alternative: GELLO Teleoperation

For higher-quality demonstrations, we recommend using GELLO, which provides smooth continuous motion capture and intuitive kinesthetic teaching. Note that GELLO does not natively support UR3 robot arm; follow GELLO’s calibration pipeline for UR3 adaptation.

Training Pipeline

The diffusion policy training pipeline is located in: Software/diffusion_policies/

Key Components

- Multi-modal observation encoding: Workspace camera, dual-zone suction camera, robot state
- Multi-head attention fusion: Coordinates central and peripheral observations (8 heads, 512 dimensions)
- Diffusion policy: Generates action trajectories with illumination and valve control
- Action chunking: 8-step history, 48-step prediction horizon

Training Configuration

- Framework: PyTorch with Hydra configuration
- GPU: RTX 4090 or equivalent recommended
- Optimizer: AdamW with cosine annealing
- Training: 500 epochs, batch size 16
- Dataset size: 100–150 demonstrations per task
Refer to Software/diffusion_policies/README.md for detailed training instructions.

### Pneumatic System Setup

Vacuum Mode

Equipment Requirements

- Vacuum pump: 750W, 140 L/min flow rate
- Maximum pressure: −90 kPa
- Operating pressure: −80 kPa (recommended)
- Solenoid valve: Normally closed, 3.7 V compatible

Performance Characteristics

- Normal force: 41.5 N (mean) at −80 kPa
- Shear force: 8.34 N (mean)
- Contact type: Sustained contact with continuous tactile feedback

FlexiCup Fabrication and Deployment Guide | 9

Bernoulli Mode

Equipment Requirements

- Air compressor: 800W, 65 L/min flow rate
- Supply pressure: Up to 0.8 MPa
- Solenoid valve: Normally closed, 3.7 V compatible

Performance Characteristics

- Lifting mechanism: Contactless aerodynamic lifting
- Contact force: Near-zero during lifting phase
- Application: Delicate surfaces (e.g., semiconductor wafers)

Mode Switching

To switch between vacuum and Bernoulli modes:

### 1. Power off the system 2. Disconnect current pneumatic source 3. Unscrew and remove bottom housing 4. Install alternative bottom housing (vacuum or Bernoulli configuration) 5. Connect appropriate pneumatic source 6. Power on and verify operation

Note: All sensing and control components remain unchanged during mode switching, demonstrating sensing-actuation decoupling.

### System Integration and Testing

Robot Arm Integration

The system has been validated with UR3 robot arm. Integration steps:

### 1. Mechanical mounting: Attach suction cup top housing to robot end-effector 2. Pneumatic routing: Connect pneumatic line from source to suction cup 3. Wireless communication: Configure UDP communication between robot controller and

ESP32

### 4. Coordinate calibration: Calibrate camera frame relative to robot base frame

Validation Tests

Basic Functionality Tests

- Wireless connectivity: Verify Wi-Fi connection and image streaming
- Pneumatic sealing: Test vacuum/pressure holding capability
- Modality switching: Verify LED control and vision-tactile transitions
- Battery operation: Confirm 30-minute runtime

Perception Tests

- Dual-zone imaging: Verify central and peripheral zone clarity
- Tactile sensitivity: Test contact detection and deformation imaging
- Object recognition: Validate multimodal classification accuracy

FlexiCup Fabrication and Deployment Guide | 10

Manipulation Tests

- Modular grasping: Test perception-driven approach on various objects
- Learning-based control: Validate diffusion policy on trained tasks
- Mode comparison: Compare vacuum and Bernoulli performance

### Troubleshooting

Common Issues

Wireless Connectivity Problems

- Verify Wi-Fi credentials in firmware
- Check antenna connection and PCB antenna design
- Ensure adequate signal strength in operating environment

Pneumatic Sealing Issues

- Inspect O-ring for damage or improper seating
- Verify PDMS membrane installation without wrinkles
- Check sealing skirt contact around perimeter
- Ensure proper housing thread engagement

Camera Image Quality

- Adjust exposure and gain parameters in firmware
- Verify fisheye lens focus and cleanliness
- Check LED illumination intensity for tactile mode
- Ensure light diffuser is properly positioned

Battery Performance

- Verify charging circuit functionality
- Check battery capacity and health
- Monitor thermal generation during operation
- Consider higher-capacity battery for extended runtime

Advanced Debugging

- Serial Monitor: Use idf.py -p /dev/ttyUSB0 monitor for real-time debugging
- Network Debugging: Use Wireshark or similar tools to verify UDP packet transmission and image streaming
- Pneumatic Testing: Use pressure gauges to verify vacuum/pressure levels and identify leaks

### Future Improvements

Hardware Enhancements

- Camera upgrade: Integrate newer sensors (OV5647, IMX219) for improved resolution and stability
- Integrated sealing: Develop fully flexible visuotactile membrane without separate sealing skirt

FlexiCup Fabrication and Deployment Guide | 11
- Thermal management: Improve heat dissipation for extended operation
- Modular configurations: Expand bottom housing options for diverse applications

Firmware Enhancements

- Onboard processing: Implement edge inference for reduced latency
- Adaptive exposure: Dynamic camera parameter adjustment based on lighting conditions
- Multi-device coordination: Support multiple FlexiCup units in collaborative tasks

Learning Pipeline Enhancements

- Improved teleoperation: Integrate GELLO or similar devices for higher-quality demonstrations
- Sim-to-real transfer: Develop simulation environments for policy pre-training
- Multi-task learning: Train unified policies across diverse manipulation tasks

### Conclusion

This guide provides comprehensive instructions for fabricating, assembling, and deploying the FlexiCup system. The modular design enables rapid reconfiguration between vacuum and Bernoulli modes while maintaining identical sensing and control pipelines. We encourage the community to build upon this work, explore the fluid dynamics phenomena observed during assembly, upgrade to newer camera modules, and develop improved teleoperation interfaces for higher-quality robot learning.

Thank you for your interest in FlexiCup!

References

For additional information, please refer to:
- Hardware designs: Hardware/Fabrication/
- Firmware source code: Hardware/Firmware/ESPCAM/
- Learning pipeline: Software/diffusion_policies/
- Experimental videos: Companion website
- Research paper: PDF/paper.pdf

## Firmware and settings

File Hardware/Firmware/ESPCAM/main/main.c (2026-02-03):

#include "wifiConnect.h"
#include "httpServer.h"
#include "camera.h"

#define CAMERA_MODEL_AI_THINKER // Has PSRAM

void app_main(void)
{
    char isConnectedFlag = 0;

    ESP_LOGI("main","start wifi sta");
    wifi_init_sta((char *)wifiName,(char *)wifiPassword,&isConnectedFlag);  /* 连接指定的wifi */
    ESP_LOGI("wifiConnect","state = %d",isConnectedFlag);                   /* 判断连接是否成功 */
    if(isConnectedFlag == 0)                                                
    {
        writeWifiInfo((unsigned char *)"111",(unsigned char *)"111",(unsigned char *)"111",1111,(unsigned char *)"fail");   /* 连接失败处理 */
        esp_restart();/* 重启设备 */
    }
    else if(isConnectedFlag == 1)/* 连接成功处理 */
    {
        appInit();
    }   


}

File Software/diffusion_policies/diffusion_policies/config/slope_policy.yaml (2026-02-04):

defaults:
  - task: slope_task
  - _self_

name: slope_policy
_target_: diffusion_policies.workspace.train_diffusion_unet_image_workspace.TrainDiffusionUnetImageWorkspace

task_name: ${task.name}
shape_meta: ${task.shape_meta}

# Global parameters
horizon: 48
n_obs_steps: 8
n_action_steps: 24
n_latency_steps: 0
num_inference_steps: 100
val_ratio: 0.1
fps: 30
zarr_path: /mnt/ubuntu/projects/DemoGen/data/slope_task_dataset/dataset_slope_official.zarr

# Policy configuration with Cross Attention
policy:
  _target_: diffusion_policies.policy.diffusion_unet_hybrid_image_policy.DiffusionUnetHybridImagePolicy
  
  shape_meta: ${shape_meta}
  
  # Noise scheduler
  noise_scheduler:
    _target_: diffusers.schedulers.scheduling_ddpm.DDPMScheduler
    num_train_timesteps: 100
    beta_schedule: squaredcos_cap_v2
    clip_sample: True
    prediction_type: epsilon
  
  # Basic parameters
  horizon: ${horizon}
  n_action_steps: ${n_action_steps}
  n_obs_steps: ${n_obs_steps}
  num_inference_steps: ${num_inference_steps}
  
  # ESP Cross Attention parameters
  enable_esp_cross_attention: True
  esp_feature_dim: 512
  esp_num_heads: 8
  esp_dropout: 0.1
  
  # Observation conditioning
  obs_as_global_cond: True
  
  # Network architecture
  diffusion_step_embed_dim: 256
  down_dims: [256, 512, 1024]
  kernel_size: 5
  n_groups: 8
  condition_type: film
  
  # Encoder configuration
  obs_encoder_group_norm: True
  eval_fixed_crop: False
  crop_shape: [76, 76]
  
  # Depth configuration (not used for slope task)
  use_depth: False
  use_depth_only: False

# EMA configuration
ema:
  _target_: diffusion_policies.model_dp_umi.diffusion.ema_model.EMAModel
  update_after_step: 0
  inv_gamma: 1.0
  power: 0.75
  min_value: 0.0
  max_value: 0.9999

# Dataloader configuration
dataloader:
  batch_size: 16
  num_workers: 2
  shuffle: True
  pin_memory: True
  persistent_workers: True

# Validation dataloader
val_dataloader:
  batch_size: 16
  num_workers: 2
  shuffle: False
  pin_memory: True
  persistent_workers: True

# Optimizer configuration
optimizer:
  _target_: torch.optim.AdamW
  lr: 1.0e-4
  betas: [0.95, 0.999]
  eps: 1.0e-8
  weight_decay: 1.0e-6

# Training configuration
training:
  device: cuda:0
  seed: 42
  debug: False
  resume: True
  lr_scheduler: cosine
  lr_warmup_steps: 500
  num_epochs: 3000
  max_train_steps: null
  max_val_steps: null
  freeze_encoder: False
  tqdm_interval_sec: 1.0
  gradient_accumulate_every: 1
  use_ema: True
  rollout_every: 50
  checkpoint_every: 50
  val_every: 1
  sample_every: 5

# Logging configuration
logging:
  project: slope_task
  resume: True
  mode: online
  name: ${now:%Y.%m.%d-%H.%M.%S}_${name}_${task.name}
  id: null
  group: null

# Checkpoint configuration
checkpoint:
  topk:
    monitor_key: val_loss
    mode: min
    k: 5
    format_str: 'epoch={epoch:04d}-val_loss={val_loss:.3f}.ckpt'
  save_last_ckpt: True
  save_last_snapshot: False

# Multi-GPU configuration
multi_run:
  run_dir: data/outputs/${now:%Y.%m.%d}/${now:%H.%M.%S}_${name}_${task.name}
  wandb_name_base: ${now:%Y.%m.%d-%H.%M.%S}_${name}_${task.name}

# Hydra configuration
hydra:
  job:
    override_dirname: ${name}
  run:
    dir: data/outputs/${now:%Y.%m.%d}/${now:%H.%M.%S}_${name}_${task.name}
  sweep:
    dir: data/outputs/${now:%Y.%m.%d}/${now:%H.%M.%S}_${name}_${task.name}
    subdir: ${hydra.job.num}

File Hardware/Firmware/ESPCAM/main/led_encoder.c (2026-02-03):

/*
 * SPDX-FileCopyrightText: 2021-2022 Espressif Systems (Shanghai) CO LTD
 *
 * SPDX-License-Identifier: Apache-2.0
 */

#include "esp_check.h"
#include "led.h"

static const char *TAG = "led_encoder";

typedef struct {
    rmt_encoder_t base;
    rmt_encoder_t *bytes_encoder;
    rmt_encoder_t *copy_encoder;
    int state;
    rmt_symbol_word_t reset_code;
} rmt_led_strip_encoder_t;

static size_t rmt_encode_led_strip(rmt_encoder_t *encoder, rmt_channel_handle_t channel, const void *primary_data, size_t data_size, rmt_encode_state_t *ret_state)
{
    rmt_led_strip_encoder_t *led_encoder = __containerof(encoder, rmt_led_strip_encoder_t, base);
    rmt_encoder_handle_t bytes_encoder = led_encoder->bytes_encoder;
    rmt_encoder_handle_t copy_encoder = led_encoder->copy_encoder;
    rmt_encode_state_t session_state = 0;
    rmt_encode_state_t state = 0;
    size_t encoded_symbols = 0;
    switch (led_encoder->state) {
    case 0: // send RGB data
        encoded_symbols += bytes_encoder->encode(bytes_encoder, channel, primary_data, data_size, &session_state);
        if (session_state & RMT_ENCODING_COMPLETE) {
            led_encoder->state = 1; // switch to next state when current encoding session finished
        }
        if (session_state & RMT_ENCODING_MEM_FULL) {
            state |= RMT_ENCODING_MEM_FULL;
            goto out; // yield if there's no free space for encoding artifacts
        }
    // fall-through
    case 1: // send reset code
        encoded_symbols += copy_encoder->encode(copy_encoder, channel, &led_encoder->reset_code,
                                                sizeof(led_encoder->reset_code), &session_state);
        if (session_state & RMT_ENCODING_COMPLETE) {
            led_encoder->state = 0; // back to the initial encoding session
            state |= RMT_ENCODING_COMPLETE;
        }
        if (session_state & RMT_ENCODING_MEM_FULL) {
            state |= RMT_ENCODING_MEM_FULL;
            goto out; // yield if there's no free space for encoding artifacts
        }
    }
out:
    *ret_state = state;
    return encoded_symbols;
}

static esp_err_t rmt_del_led_strip_encoder(rmt_encoder_t *encoder)
{
    rmt_led_strip_encoder_t *led_encoder = __containerof(encoder, rmt_led_strip_encoder_t, base);
    rmt_del_encoder(led_encoder->bytes_encoder);
    rmt_del_encoder(led_encoder->copy_encoder);
    free(led_encoder);
    return ESP_OK;
}

static esp_err_t rmt_led_strip_encoder_reset(rmt_encoder_t *encoder)
{
    rmt_led_strip_encoder_t *led_encoder = __containerof(encoder, rmt_led_strip_encoder_t, base);
    rmt_encoder_reset(led_encoder->bytes_encoder);
    rmt_encoder_reset(led_encoder->copy_encoder);
    led_encoder->state = 0;
    return ESP_OK;
}

esp_err_t rmt_new_led_strip_encoder(const led_strip_encoder_config_t *config, rmt_encoder_handle_t *ret_encoder)
{
    esp_err_t ret = ESP_OK;
    rmt_led_strip_encoder_t *led_encoder = NULL;
    ESP_GOTO_ON_FALSE(config && ret_encoder, ESP_ERR_INVALID_ARG, err, TAG, "invalid argument");
    led_encoder = calloc(1, sizeof(rmt_led_strip_encoder_t));
    ESP_GOTO_ON_FALSE(led_encoder, ESP_ERR_NO_MEM, err, TAG, "no mem for led strip encoder");
    led_encoder->base.encode = rmt_encode_led_strip;
    led_encoder->base.del = rmt_del_led_strip_encoder;
    led_encoder->base.reset = rmt_led_strip_encoder_reset;
    // different led strip might have its own timing requirements, following parameter is for WS2812
    rmt_bytes_encoder_config_t bytes_encoder_config = {
        .bit0 = {
            .level0 = 1,
            .duration0 = 0.3 * config->resolution / 1000000, // T0H=0.3us
            .level1 = 0,
            .duration1 = 0.9 * config->resolution / 1000000, // T0L=0.9us
        },
        .bit1 = {
            .level0 = 1,
            .duration0 = 0.9 * config->resolution / 1000000, // T1H=0.9us
            .level1 = 0,
            .duration1 = 0.3 * config->resolution / 1000000, // T1L=0.3us
        },
        .flags.msb_first = 1 // WS2812 transfer bit order: G7...G0R7...R0B7...B0
    };
    ESP_GOTO_ON_ERROR(rmt_new_bytes_encoder(&bytes_encoder_config, &led_encoder->bytes_encoder), err, TAG, "create bytes encoder failed");
    rmt_copy_encoder_config_t copy_encoder_config = {};
    ESP_GOTO_ON_ERROR(rmt_new_copy_encoder(&copy_encoder_config, &led_encoder->copy_encoder), err, TAG, "create copy encoder failed");

    uint32_t reset_ticks = config->resolution / 1000000 * 50 / 2; // reset code duration defaults to 50us
    led_encoder->reset_code = (rmt_symbol_word_t) {
        .level0 = 0,
        .duration0 = reset_ticks,
        .level1 = 0,
        .duration1 = reset_ticks,
    };
    *ret_encoder = &led_encoder->base;
    return ESP_OK;
err:
    if (led_encoder) {
        if (led_encoder->bytes_encoder) {
            rmt_del_encoder(led_encoder->bytes_encoder);
        }
        if (led_encoder->copy_encoder) {
            rmt_del_encoder(led_encoder->copy_encoder);
        }
        free(led_encoder);
    }
    return ret;
}

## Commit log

2025-11-17 Update project metadata and documentation
    - Correct title to 'Dual-Zone Vision-Tactile Sensing'
    - Update README with accurate system description
    - Fix meta tags and keywords in HTML
    - Emphasize dual-zone sensing architecture
    - Update technical specifications (30Hz, not 60Hz)
2026-02-03 Activate Hardware and Firmware buttons with GitHub links
    - Remove disabled styling from Hardware and Firmware buttons
    - Add GitHub repository links for Hardware and Code sections
    - Update .gitignore to exclude large files
    - Remove acceptance notice text
2026-02-03 Add optimized videos and video optimization tools
    - Compressed all videos using FFmpeg (92.5% size reduction: 163.8MB → 12.2MB)
    - Updated HTML to use optimized videos with preload='none'
    - Added video optimization script with automatic ffmpeg download
    - Set up Git LFS to track large files (*.mp4, *.STEP, ffmpeg-static)
    - Significant performance improvement for web loading
2026-02-03 Add Hardware and Code directories with documentation
    - Add README files for Hardware and Code directories
    - Create PCB subdirectory structure
    - Set up Git LFS tracking for large CAD files
    - Ensure directories are visible on GitHub
2026-02-03 Convert optimized videos from LFS to regular Git files
    - Remove LFS tracking for small optimized videos (<10MB each)
    - Update .gitattributes to only track large original videos with LFS
    - Change video paths back to relative URLs for GitHub Pages compatibility
    - Total optimized videos size: 12.2MB (well under GitHub limits)
    - Fixes video loading issues on GitHub Pages
2026-02-03 Add complete project files and enable video autoplay
    - Enable video autoplay with muted and loop attributes
    - Update button links to anonymous submission site
    - Add comprehensive README.md with project structure
    - Add complete Hardware files (CAD models, PCB designs, BOMs)
    - Add complete Firmware code (ESP32S3 camera firmware)
    - All videos now autoplay on page load with controls available
    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
    [FlexiCup_CAD_BOM.xlsx, FlexiCup_PCB_BOM.xlsx]
2026-02-03 Add CAD STEP files with Git LFS
    - Add all 7 STEP files to repository via Git LFS
    - FlexiCup_Vacuum.STEP (110MB)
    - FlexiCup_Bernoulli.STEP (110MB)
    - 4 modular bottom configurations (390KB-975KB)
    - Suction cup top (398KB)
    - Update .gitignore to allow STEP files
    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
    [FlexiCup_Bernoulli .STEP, FlexiCup_Vacuum.STEP, suction cup bottom I.STEP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]
2026-02-03 Major website update: restructure, add force characterization, wafer comparison, dynamic performance, and BC-RNN baseline
    - Restructured website with logical flow: Overview → Hardware → Characterization → Applications
    - Added detailed side navigation with subsections
    - Added sensor-based force characterization (41.50N normal, 8.34N tangential)
    - Added wafer pick-up comparison (non-contact verification)
    - Added dynamic performance demonstrations at realistic speeds
    - Added BC-RNN baseline comparison showing diffusion policy advantages
    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
2026-02-04 Update terminology: Hardware → Fabrication, Code → Firmware
    - Renamed Hardware/ directory to Fabrication/
    - Renamed Code/ directory to Firmware/
    - Updated .gitattributes to reflect new directory paths
    - Updated README files with new terminology
    - All displayed content now uses Fabrication and Firmware terminology
    [FlexiCup_Bernoulli .STEP, FlexiCup_CAD_BOM.xlsx, FlexiCup_PCB_BOM.xlsx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]
2026-02-04 Polish website content for better flow and readability
    - Simplified and streamlined text descriptions
    - Improved transitions between sections
    - Unified terminology and expression style
    - Removed redundant hidden sections
    - Enhanced technical detail presentation
    - Made content more concise and impactful
2026-02-04 Simplify baseline comparison section to blend naturally
    - Removed blue border and background color that made it too prominent
    - Changed to simple paragraph + videos layout
    - Reduced caption emphasis (smaller font, lighter color)
    - Made it feel like a natural continuation rather than special callout
    - Overall more subtle and integrated with main content flow
2026-02-04 Reorganize project structure: Hardware + Software separation
    - Restructured directories: Hardware/ (Fabrication + Firmware) and Software/ (diffusion_policies)
    - Updated HTML buttons: Fabrication/Firmware → Hardware/Software
    - Comprehensive README.md update reflecting new structure
    - Updated .gitattributes for new Hardware/Fabrication paths
    - Added Hardware/README.md and Software/README.md with detailed documentation
    - Software section includes complete ML pipeline: data collection, training, evaluation, deployment
    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
    [FlexiCup_Bernoulli .STEP, FlexiCup_CAD_BOM.xlsx, FlexiCup_PCB_BOM.xlsx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]
2026-02-09 Add tutorial documentation: English translation (TUTORIAL.md) and Chinese original (教程.md), update README and index.html with tutorial link
2026-02-24 Remove PDF files from LFS, store as regular Git files
    - Updated .gitattributes to exclude PDF files from LFS
    - Only Hardware/Fabrication/PCB/*.pdf still uses LFS
    - PDF/paper.pdf (4.9MB) and PDF/TUTORIAL.pdf (110KB) now stored directly in Git
    - This ensures PDFs are accessible on GitHub Pages without LFS issues
